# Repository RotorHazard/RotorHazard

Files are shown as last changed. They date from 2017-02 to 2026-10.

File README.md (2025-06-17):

RotorHazard Logo

# RotorHazard
**FPV Race Timing and Event Management**

RotorHazard is an open-source timing and event management system for FPV drone racing. It tracks the video signals broadcast by race drones to trigger lap times, and processes them with a central server (usually a Raspberry Pi). The server's front-end web interface provides race organizer management, pilot/spectator information, and race results. Supports up to 16 simultaneous racers.

> [!TIP]
>Join a community to discuss RotorHazard: [Discord](https://discord.gg/ANKd2pzBKH) | [Facebook](https://www.facebook.com/groups/rotorhazard)
>
> Sponsor RtorHazard's development:[GitHub](https://github.com/sponsors/HazardCreative) | [Patreon](https://www.patreon.com/rotorhazard)

## Features
* Self-contained on local hardware, no internet connection needed
* Server synchronized with user interface for accurate start/end signals; compensates for poor network connectivity
* Connect other systems and extend functionality via [plugins](doc/Plugins.md)
* Server runs on any device supporting Python

### Timing
* Verified accuracy by independent 3rd party testing
* **Never miss a lap**; Recover laps with full accuracy by reviewing race history (marshaling)
* Accurately tracks analog and digital (HD) video transmitters
* Simple visual system calibration before or after a race has completed
* Learns which calibration values work for each pilot and automatically applies them to new races (adaptive calibration)
* Advanced signal filtering allows accurate reading both indoors and outdoors, even in difficult multipathing environments

### Event Management
* Run events with hundreds of pilots and race heats
* Manage pilots, heats, classes, and race formats before or after races are run
* Supports common event/race formats and ranking structures; extensible by plugin
* Statistics broken out by event, class, heat, and round
* Generates overlay displays and results pages for use with live streaming software such as OBS
* LED and audio support indicate race staging, starts, lap times, and other events
* Send live updates of lap times and split times to external systems such as pilot OSD

<br />

## Getting Started

RotorHazard consists of three primary components: Timing hardware, server, and frontend interface. **Most users will begin with RotorHazard by building or buying timing hardware and then installing the server software on it.**

> [!IMPORTANT]
> Live documentation may contain information that does not apply to the current release. For documentation relating to the *current stable version only*, follow the [Documentation](https://github.com/RotorHazard/RotorHazard/releases/latest#documentation) link on the [latest-release page](https://github.com/RotorHazard/RotorHazard/releases/latest).

### Timing Hardware

RotorHazard makes use of a collection of RX5808 video receiver modules. Receivers are tuned to active FPV race channels and monitor their signal strength. A small but dedicated processor (Arduino or STM32) is used to monitor the modules and communicate with the server. Timer builds generally include hardware to run the server as well, making a self-contained unit.

- Choose a style from the available [Build Resources](resources/README.md). Build styles include circuit boards, BOM, and 3D-printable cases.
- [Delta5 Race Timer](https://github.com/scottgchin/delta5_race_timer) hardware is still supported and runs with full accuracy. Replace the Delta5 server software using the current RotorHazard server [setup instructions](doc/Software%20Setup.md), ensuring that you complete a [re-flash of the Arduinos](doc/Software%20Setup.md#rotorhazard-node-code).

### Server

The RotorHazard server aggregates timing signals, handles event structure, calculates results, provides the management interface, and communicates with external timers and systems. It can be run on most systems where Python can be installed, but the recommended and best supported installation is to a **Raspberry Pi**.

> [!NOTE]
> The [RotorHazard Install Manager](https://github.com/RotorHazard/RH_Install-Manager) can greatly simplify installation. Once you have installed the operating system to your SD card, download and run the Install Manager.

> [!IMPORTANT]
> The 'main' branch in the GitHub repository will usually contain the latest development code, which may not be stable. To install or upgrade to the latest stable release, please visit the [latest-release page](https://github.com/RotorHazard/RotorHazard/releases/latest).

### Frontend (Event Management) Interface

The frontend interface is used for event management and viewing results. The server can be accessed by any device (laptop, phone, tablet) with a modern web browser (Firefox, Chrome, Safari) on any operating system (Windows, MacOS, Android, iOS).

- Once the server is running, connect to the server's address using standard IP-based networking.
- All event management is done through the interface.
- No dedicated software or app is necessary to access the interface.

<br />

## Additional Resources

RotorHazard's features and functionality can be greatly extended beyond the core system.

### Plugins

Plugins allow 3rd parties to develop code which runs on the RotorHazard server.
- "Community Plugins" may be found within RotorHazard's interface. From here, plugins are easily downloaded, installed, and upgraded.
- See [Plugins](doc/Plugins.md) for information on manual installation.
- Individual plugins may have specific setup requirements. Read each plugin's documentation before use.

### Wiki

Many additional resources are available from the [Wiki](https://github.com/RotorHazard/RotorHazard/wiki), including extended tutorials, build tools, SD card images, and video content. Browsing these resources is strongly recommended for new users.

<br />

## Feedback

To report bugs or request features, please [post a GitHub issue](https://github.com/RotorHazard/RotorHazard/issues). When reporting issues, use the "Download Logs" button and include the generated '.zip' file.

Community contributions are welcome and encouraged; see [Development](doc/Development.md) for more information.

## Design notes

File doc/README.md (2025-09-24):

# RotorHazard Documentation

## Timing Guides
* [User Guide](User%20Guide.md)
* [Calibration Guide](Tuning%20Parameters.md)
* [Shielding and Course Position](Shielding%20and%20Course%20Position.md)
* [Event Setup Guide](Event%20Setup%20Guide.md)

## System Reference
* [Hardware Setup Instructions](Hardware%20Setup.md)
* [Software Setup Instructions](Software%20Setup.md)
* [Raspberry Pi Reference](Raspberry%20Pi%20Reference.md)
* [Windows Run Script](Windows%20Run%20Script.md)

## Optional Features
* [Plugins](Plugins.md)
* [Split Timing Guide](Cluster.md)
* [USB Nodes](USB%20Nodes.md)

## General Reference
* [FPV Frequency Reference Chart](Frequency%20Reference.md)

<br />

---

* [Build Resources (PCB, etc) &#10132;&#xFE0E;](https://github.com/RotorHazard/RotorHazard/tree/main/resources/README.md)
* [Developer Documentation](Development.md)
* <a href="https://github.com/RotorHazard/RotorHazard">RotorHazard on GitHub &#10132;&#xFE0E;</a>

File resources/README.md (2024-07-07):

# RotorHazard Hardware Build Resources

All supported build styles offer full timing accuracy but differ in size, cost, and ease of use.

<br />

## Full-featured S32_BPill

Standard, current build using the STM32 "Blue Pill" in place of individual Arduinos. Recommended for event managers with the available time and resources to acquire parts and complete the build.

- Supports up to 8 receivers (or more via USB)
- Supports all optional hardware features: current sensing, voltage sensing, RTC, buzzer, Status LED
- Ease-of-use features: power switch, shutdown button

### Full-size
[RotorHazard S32_BPill PCB](S32_BPill_PCB/)<br />
[RotorHazard S32_BPill Case](S32_BPill_case/)

### Compact (supports up to 6 receivers)
[RotorHazard 6 Node STM32](6_Node_BPill_PCB/)<br />
[RotorHazard 6 Node Case](6_node_BPill_case/)

<br />

## NuclearHazard Core

Designed for PCB manufacturer to be able to populate components instead of ordering individually. Available for purchase from the board designer.

- Supports up to 8 receivers (or more via USB)
- Supports buzzer
- Lowest cost self-contained build
- Smallest size
- Simplest assembly

[NuclearHazard Core (Prepopulated S32)](NuclearHazardCore/)

### NuclearHazard Atom

A compact, 2-node version of the NuclearHazard

[NuclearHazard Atom (2-node Prepopulated S32)](NuclearHazardAtom/)

<br />

## Arduino PCB

Uses the same basic hardware as the Delta 5, with improved features and ease of use.

- Supports up to 8 receivers when paired with second PCB (or more via USB)
- Highest cost for required components

[RotorHazard/Arduino PCB](PCB/)<br />
[3D Printed Enclosure for Arduino-based PCBs](enclosure/)

<br />

## Delta 5

Existing Delta 5 builds may be used but are not recommended for new builds.

- Supports up to 8 receivers when paired with second PCB (or more via USB)
- Highest cost for required components
- Arduinos must be manually addressed with code modification
- Arduinos must be removed to reprogram

Replace the Delta5 server software using the current RotorHazard server [setup instructions](doc/Software%20Setup.md), ensuring that you complete a [re-flash of the Arduinos](doc/Software%20Setup.md#rotorhazard-node-code).

<br />

## USB Node

Receivers may be connected to servers via USB insterface.

- Very low cost
- Does not contain server hardware; must connect to an existing server (for example, one of the above builds or installed directly onto a laptop)

[USB Nodes](../doc/USB%20Nodes.md)

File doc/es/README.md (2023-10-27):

# Documentación RotorHazard

## Guías de Configuración
* [Guía de Usuario](User%20Guide.md)
* [Guía de Calibrado](Tuning%20Parameters.md)
* [Blindaje Señal y Posición en Carrera](Shielding%20and%20Course%20Position.md)
* [Guía de Configuración de Evento](Event%20Setup%20Guide.md)

## Referencia del Sistema
* [Instrucciones de Configuración de Hardware](Hardware%20Setup.md)
* [Instrucciones de Configuración de Software](Software%20Setup.md)
* [Raspberry Pi Referencia y Notas](Raspberry%20Pi%20Reference.md)

## Características Opcionales
* [Plugins](Plugins.md)
* [Configuración Cronos Secundarios (Racimo)](Cluster.md)
* [Nodos USB](USB%20Nodes.md)
* [Control de Receptores de Vídeo](Video%20Receiver.md)

## Referencia General
* [Tabla de Referencia de Frecuencias FPV](Frequency%20Reference.md)

<br />

---

* [Recursos de Construcción (PCB, etc.) &#10132;&#xFE0E;](https://github.com/RotorHazard/RotorHazard/tree/main/resources/README.md)
* [Documentación del Desarrollador](Development.md)
* <a href="https://github.com/RotorHazard/RotorHazard">RotorHazard en GitHub &#10132;&#xFE0E;</a>

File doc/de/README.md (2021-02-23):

# RotorHazard-Dokumentation

## Timing-Leitfäden

* [Benutzerhandbuch](User%20Guide.md)
* [Kalibrierungsanleitung](Tuning%20Parameters.md)
* [Abschirmung und Kursposition](Shielding%20and%20Course%20Position.md)
* [Anleitung zur Ereigniseinrichtung](Event%20Setup%20Guide.md)

## System-Referenz

* [Anweisungen zur Hardware-Einrichtung](Hardware%20Setup.md)
* [Software-Einrichtungsanweisungen](Software%20Setup.md)
* [Raspberry Pi Reference](Raspberry%20Pi%20Reference.md)

## Optionale Merkmale

* [Leitfaden zur Zeitaufteilung](Cluster.md)
* [USB-Knoten](USB%20Nodes.md)
* [Video-Empfängersteuerung](Video%20Receiver.md)

## Allgemeine Referenz

* [FPV-Frequenz-Referenzdiagramm](Frequency%20Reference.md)

<br />

---

* [Dokumentation für Entwickler](Development.md)
* <a href="https://github.com/RotorHazard/RotorHazard" target="_blank">RotorGefahr auf GitHub</a> &#10132;➔&#xFE0E;︎

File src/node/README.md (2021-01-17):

# Receiver Node Firmware

The `src/node` directory contains the source code for the RotorHazard nodes. The same code may be used on Arduino nodes, or on an S32_BPill multi-node board.

For Arduino nodes, see '[readme_Arduino.md](readme_Arduino.md)'

For S32_BPill nodes, see '[readme_S32_BPill.md](readme_S32_BPill.md)'

<br>

## Unit Tests

Setup as per <https://github.com/Arduino-CI/arduino_ci>, then

```
set path=c:\Ruby25-x64\msys64\mingw64\bin;%path%
bundle exec arduino_ci_remote.rb --skip-compilation
```

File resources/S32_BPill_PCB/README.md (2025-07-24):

# RotorHazard S32_BPill PCB

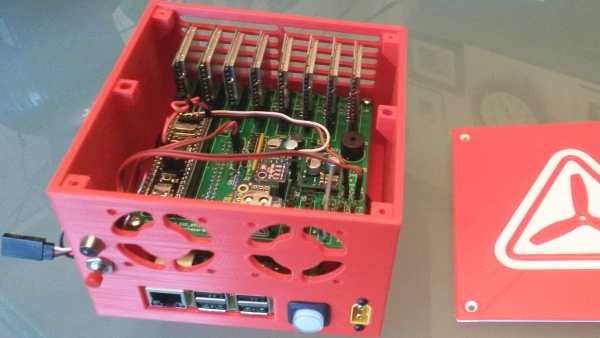
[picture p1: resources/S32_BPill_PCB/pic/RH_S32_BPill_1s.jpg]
RH_S32_BPill_1


The RotorHazard S32_BPill PCB v1.0 represents the next generation of race-timer hardware.

## Features

* Instead of multiple Arduinos, the board has a single STM32 processor

* Board size (100x100mm) is the same as the "standard" Delta5 PCBs

* Supports 1 to 8 RX5808 node modules on a single PCB

* The RX5808 node modules are mounted vertically using small sub-boards -- this allows for up to eight on a single board, and provides substantially improved cooling

* Communication between the STM32 processor and the Raspberry Pi is via serial-port link, running at 921600 baud. The S32_BPill board can also be connected directly to a computer by attaching a USB-to-Serial/FTDI dongle to the J4 (BPill_FTDI) connector, with a baud rate of 921600 or 115200.

* The STM32 processor is on a 40-pin module, attached to the board via sockets. These are commonly known as "Blue Pill" modules, and are readily available and inexpensive (see [below](#aboutblue))

* The board has a 40-pin (2x20) header for connecting to the Raspberry Pi, via a [ribbon cable](https://www.ebay.com/itm/40-Pin-2x20-Female-to-Female-2-54mm-Pitch-40-wire-IDC-Flat-Ribbon-Cable/391776118674) with female ends

* The STM32 processor is in-circuit programmable, able to be updated/flashed using the Raspberry Pi. The update can be performed via the RotorHazard web GUI using the 'Update Nodes' button (in the 'System' section on the 'Settings' page)

* The same server and node source code supports both the S32_BPill and the (existing) multi-Arduino boards

* Supports power/battery monitoring and a buzzer (low-battery alarm)

* Mounting locations for (optional) [DS3231](#rtc) (RTC), [INA219](https://www.adafruit.com/product/904) and [BME280](https://www.amazon.com/Onyehn-Temperature-Humidity-Barometric-Pressure/dp/B07KR24P6P) modules, connected to the Raspberry Pi I2C bus

* Optional "extra" LED, which can be panel mounted on the timer case

* Connector pads for LED-strips: J6 "Pi_LED" (near the middle of the board); pin 1 is ground, pin 2 is signal (going to GPIO10 on the Raspberry Pi)
<br>

Main PCB:<br>
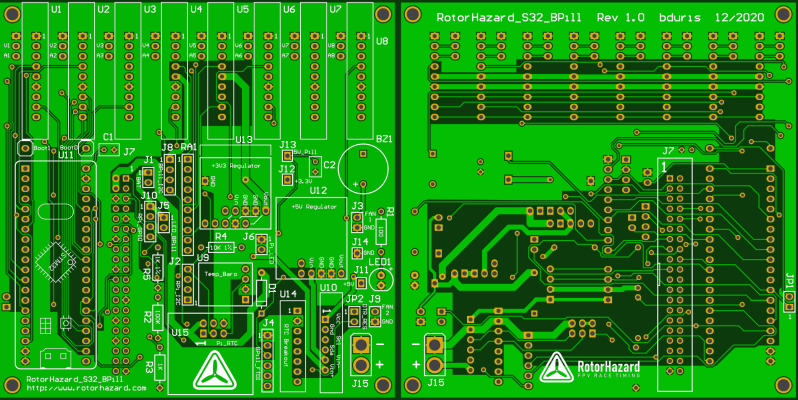
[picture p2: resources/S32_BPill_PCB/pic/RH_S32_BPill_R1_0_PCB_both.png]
RH_S32_BPill_R1_0_PCB_both
<br><br>
Node PCB:<br>
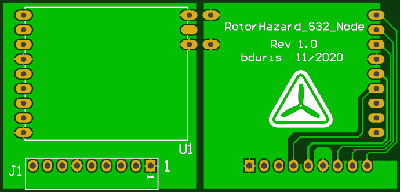
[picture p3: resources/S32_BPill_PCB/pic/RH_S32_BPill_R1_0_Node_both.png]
RH_S32_BPill_R1_0_Node_both


## Resources

[RotorHazard S32_BPill PCB Schematic](files/RotorHazard_S32_BPill_SCH_R1.pdf)

[RotorHazard S32_BPill Node-board Schematic](files/RotorHazard_S32_Node_SCH_R1_0.pdf)

[Gerber files for RotorHazard S32_BPill PCB](http://www.rotorhazard.com/files/GerberFiles_RotorHazard_S32_BPill_R1.zip) &nbsp; (alternate link: [on GitHub](files/GerberFiles_RotorHazard_S32_BPill_R1.zip))

[Gerber files for RotorHazard S32_BPill Node board](http://www.rotorhazard.com/files/GerberFiles_RotorHazard_S32_Node_R1_0.zip) &nbsp; (alternate link: [on GitHub](files/GerberFiles_RotorHazard_S32_Node_R1_0.zip))

The Gerber files can be sent to a PCB manufacturer to fabricate boards. To build a timer, you will need one S32_BPill PCB, and several of the S32_BPill Node boards (one for each RX5808 module in the timer).

The size of the node board is 34.3x33.0mm, with a recommended thickness of 0.8mm (for better thermal conductivity and more capacitance between layers). The recommended thickness for the main PCB is the standard 1.6mm, and, in general, the default PCB-fabrication settings should work well (i.e., 1oz copper, HASL finish, no castellated holes, no gold).

Bill of Materials: [PDF](files/RotorHazard_S32_BPill_R1_bd02.pdf) | [XLS](files/RotorHazard_S32_BPill_R1_bd02.xls) | [HTML](http://www.rotorhazard.com/files/RotorHazard_S32_BPill_R1_bd02.html)

[RotorHazard S32_BPill Main Board Build Guide](mainBoardBuild.md)

[RotorHazard S32_BPill Node Board Assembly](nodeAssembly.md)

[Altium 16.1 project files exported to ASCII](https://github.com/RotorHazard/rhfiles/raw/main/S32_BPill/files/RotorHazard_S32_BPill_R1_AltiumAscii.zip)

[CAD drawings of S32_BPill PCB](https://github.com/RotorHazard/rhfiles/raw/main/S32_BPill/files/RotorHazard_S32_BPill_PCB_R1.pdf)

[CAD drawings of S32_BPill Node Board](https://github.com/RotorHazard/rhfiles/raw/main/S32_BPill/files/RotorHazard_S32_Node_PCB_R1_0.pdf)

[PCB Build Notes](files/Build_notes.txt) and [Pin Soldering Helper](files/PinSolderingHelper.pdf) doc

[Socket Headers](headers.md) and [Trimming Jig](trimjig.md) for RotorHazard S32_BPill

[Generic Blue Pill Pinout](files/GenericBluePillPinout.jpg)

[RobotDyn "Black" Pill Pinout](files/STM32F103C8T6-RobotDyn_Black_Pill_pinout.pdf)

## Notes

* For the S32_BPill board the RotorHazard server must be version 3.1.0 or later.

* The recommended voltage regulators for the board are Pololu [D36V28F5](https://www.pololu.com/product/3782) (5V) and Pololu [D24V22F3](https://www.pololu.com/product/2857) (3.3V). See [here for additional notes](files/PololuCompatibilityWithRaceTimer.txt) about Pololu voltage regulators.

* The board supports two types of [Real-Time Clock](../../doc/Real%20Time%20Clock.md) (RTC) modules - '[DS3231 PiRTC](https://www.adafruit.com/product/4282)' (3x2 header U15) and '[DS3231 Breakout](https://www.adafruit.com/product/3013)' (8-pin header U14). Only one should be attached at a time. See the '[doc/Real Time Clock.md](../../doc/Real%20Time%20Clock.md)' file for setup instructions.

* The recommended installation option for the RX5808 node boards is to use [low-profile sockets](https://www.mouser.com/ProductDetail/Mill-Max/801-93-036-10-012000?qs=WZRMhwwaLl%2F7W%252BkSMqBETQ%3D%3D) in the U1-U8 (9-pin) locations on the PCB. These are shorter and have better contacts than standard socket headers. See the "[Trimming Jig for RotorHazard S32_BPill Nodes](trimjig.md)" document for information about trimming the pins on the node boards.

* An optional [INA219](https://www.adafruit.com/product/904) voltage and current-sensing module may be installed on the PCB at position U10. See [here](https://github.com/RotorHazard/rhfiles/raw/main/S32_BPill/mainBuildPics/image10.jpg) for a pic. (Make sure sure the pin designators correspond to those on the main board -- if the INA219 is installed backwards it will be destroyed.) If an INA219 is not installed, then a wire jumper needs to be soldered between the Vin+ and Vin- pins of the U10 pads (as noted on the
[schematic](https://github.com/RotorHazard/RotorHazard/blob/main/resources/S32_BPill_PCB/files/RotorHazard_S32_BPill_SCH_R1.pdf)).

* If you install the Boot0 [jumper wire](https://www.adafruit.com/product/1951) (and leave it installed) then the Raspberry Pi will always be able to flash the BPill. Without the wire, flash-updates will work if the RotorHazard firmware is operational on the BPill (it has a jump-to-bootloader command), but if not then you'd need to move the 2-pin header clip to the '1' position on Boot0. The red wire in [this pic](pic/RH_S32_BPill_Boot0Jumper.jpg) is the Boot0 jumper wire.

* Note that during the first-time power up, if the buzzer is constantly beeping (because the BPill is not yet flashed), you can put the 2-pin header-clip on the '1' position of the Boot0 jumper on the BPill module and press the reset button to silence it, and leave it on there until the initial flash of the BPill. After that, the Boot0 wire jumper should be installed and left in place. See the links above for BPill pinouts.

* There have been reports that with some BPill modules the buzzer emits a constant tone -- a workaround for this is to wire the '+' side of the buzzer to +3.3V (J12) instead of +5V.  Using a different BPill module may also fix the issue.

* The recommended method for installing the node firmware onto the BPill processor is to use the `Update Nodes` button (in the 'System' section on the 'Settings' page) on the RotorHazard web GUI. The "dtoverlay=miniuart-bt" line needs to have been added to the "/boot/config.txt" file on the RPi for the flash-update to succeed (see instructions in '[doc/Software Setup.md](../../doc/Software%20Setup.md)'). A successful update should result in [messages like these](files/BluePillFlashingMsgs.txt) being displayed and logged.

* If the initial programming of the BPill processor is unsuccessful, it may be necessary to use an [ST-Link](https://www.ebay.com/sch/i.html?_nkw=ST-Link) USB programming adapter. See the instructions in the first section of the '[src/node/readme_S32_BPill.md](../../src/node/readme_S32_BPill.md)' file and use step "[8b](../../src/node/readme_S32_BPill.md#s32stlink)" to do the flash-update.

* The recommended enclosure is the [RotorHazard S32_BPill Case](../S32_BPill_case/README.md), which features mounting holes for a power button, [shutdown button](../../doc/Shutdown%20Button.md), and status LED.

### About Blue Pill Modules

The "Blue Pill" is a module containing an STM32F1 processor and support components mounted on small board with two rows of 20-pin headers. The most common variant is what we're calling the "[Generic Blue Pill](https://stm32-base.org/boards/STM32F103C8T6-Blue-Pill)".

Any Blue Pill module with an STM32F103C8T6 processor and a compatible pin layout should work fine with the S32_BPill PCB. (Note: It needs to be the "C8" module; the STM32F103C6T6 module cannot be used because its available memory space is too small.)

Seaching eBay for "[STM32F103C8T6 Blue Pill](https://www.ebay.com/sch/i.html?_nkw=STM32F103C8T6+Blue+Pill)" should lead to a number of good, cheap options for acquiring compatible modules.

Note that there are other types of modules out there with different pinouts. It is possible (with some tweaking) to use an STM32F4 ("Black Pill") module with the S32_BPill PCB; see [here for more information](stm32f4module.md).

<br>

### Assembled RotorHazard S32_BPill Board

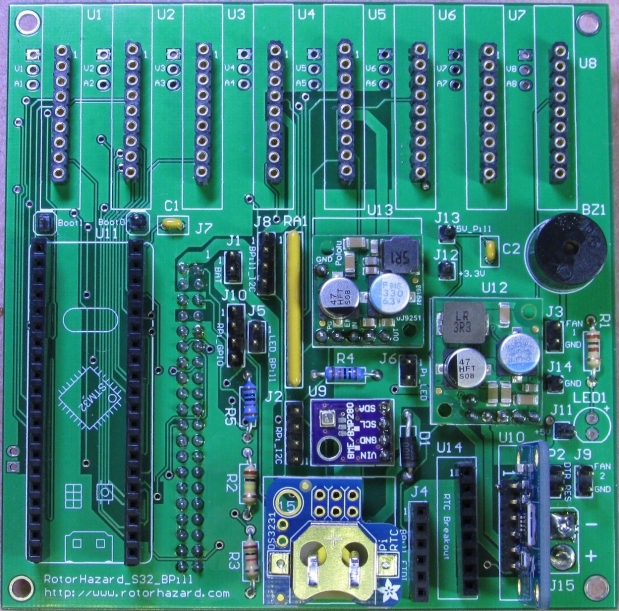
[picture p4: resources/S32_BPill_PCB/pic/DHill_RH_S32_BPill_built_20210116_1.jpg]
DHill_RH_S32_BPill_built_20210116_1


<br>

The RotorHazard S32_BPill schematic and PCB were developed by Bob Duris and [Eric Thomas](http://www.etheli.com).<br>
Special thanks to David Hill for the RotorHazard S32_BPill Main Board Build Guide, and more.

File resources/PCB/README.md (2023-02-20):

# RotorHazard PCB

The RotorHazard PCB 1.2 implements current hardware standards to simplify wiring and component placement, expediting timer builds and improving usability.

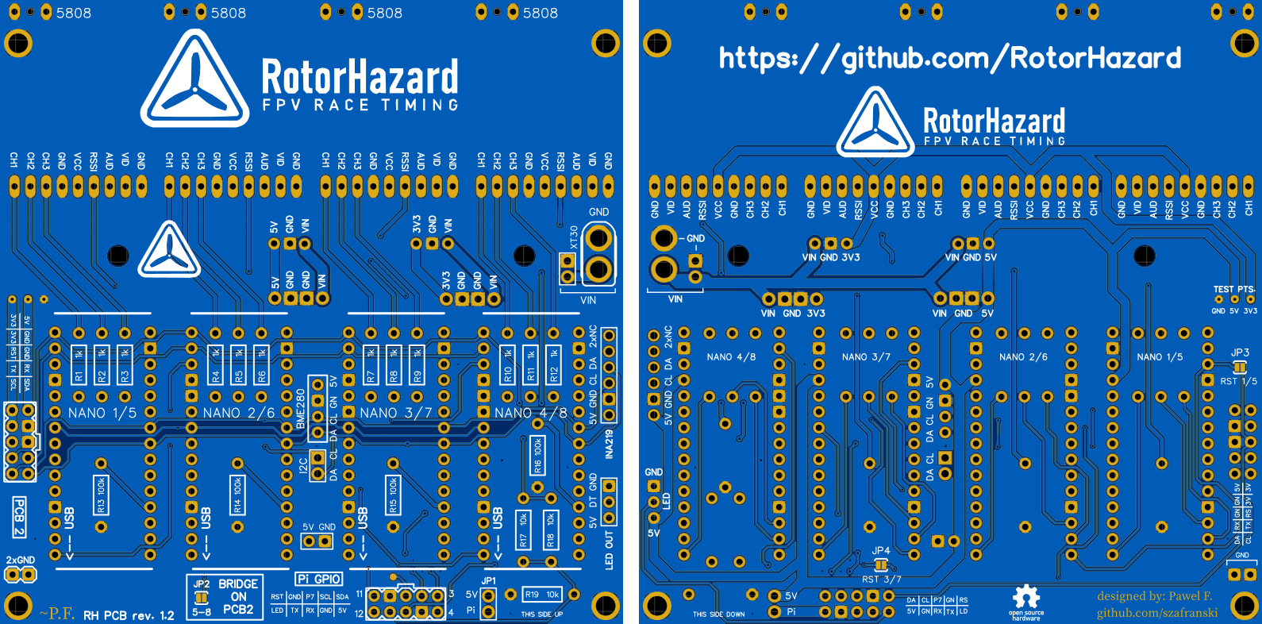
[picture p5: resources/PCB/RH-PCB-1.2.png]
PCB Layout


Download the [gerber file](Gerber_PCB%20RotorHazard%20PCB%20rev.%201.2.zip) to produce a board or send to a PCB manufacturer. Manufacturers often require bulk purchases, so check with other RotorHazard users near you before purchasing in case there is stock available or to split the cost of an order.

[View Board Schematic (PDF)](Schematic_RotorHazard-PCB-1_2_RC_2020-08-20_19-56-33.pdf)<br>
[View Board Dimensions (JPG)](RH_PCB_1_2_dimensions.jpg)

## Features

* 100×100mm (matches common Delta5 V2 PCB)
* Functions as 1–4 node primary board or 1–4 node extension
* Implements hardware-based node address selection. Nodes do not need uniquely addressed and can remain st to address 0 on upload.
* Implements in-system programming wiring for "OTA" updates without removing Arduinos from board
* Integrated voltage converter for ISP line
* Supports standardized 2×5 pin ribbon cable connectors to Pi GPIO and between boards
* Dedicated connectors for BME280 and INA219 sensors
* Expansion connectors for other I2C devices
* Raspberry Pi power isolation jumper
* Additional VIN connector (common uses: case fan or diode for reverse voltage protection)
* Additional ground connectors (common use: case shielding)
* 6 screw-mount holes, 4 with exposed ground plane

## Testing

RotorHazard does not manufacture PCBs and cannot guarantee the quality of any manufacturer. Thoroughly test any boards before connecting sensitive components.

## Build Components

### Required

See [Hardware Setup](https://github.com/RotorHazard/RotorHazard/blob/main/doc/Hardware%20Setup.md) for basic component requirements such as Arduinos, resistors, and receiver modules. The RotorHazard PCB offers mounting points for these components.

In addition to the above building with the RotorHazard PCB requires:
* 1× PCB (for timers with 1–4 nodes) or 2× PCB (timers with 5–8 nodes)
* 1× 3V 2.5A regulator
* 3× 10k resistor (0.25W or greater)

The RotorHazard PCB is designed to fit the following components:
* Arduino Nano
* Pololu D24V25F5 ("enable" pin is not connected)
* Pololu D24V25F3 ("enable" pin is not connected)

### Recommended

These components improve performance or significantly improve ease of use.

* 2×15 pin female 0.1in headers for each Arduino
* 1×9 pin female 0.1in header for each RX5808 module
* Female 0.1in header for each voltage regulator (either 1×3 pin or 1×4 pin depending on regulator style)
* 1×2 pin male 0.1in header with 2-pin jumper (for disconnecting power from the Pi)
* 2×5 pin male connector for Pi GPIO (may be KANDA/ISP style or male gold-pin header)
* Flat/ribbon cable or 10pcs jumper wires (2×5) for Pi GPIO
* 4–6 3mm screws for each board (mounting board to case)

If a 2nd PCB is used:
* 2×5 pin male connector for each PCB
* Flat/ribbon cable or 10pcs jumper wires (2×5) for PCB1 -> PCB2

### Optional

For a tidy build or to use with optional features, the following components may be added.

* XT30 female connector (power in)
* 1×3 pin female 0.1in header for each RX5808 module's antenna connector—do not solder center ANT pin
* 1×3 pin male 0.1in header for LEDs (connect only DATA and GND if LED are powered with separate voltage source)
* 1×6 pin female 0.1in header for INA219 sensor
* 1×4 pin female 0.1in header for BME280 sensor
* 1×2 0.1in header for grounding of RF shield (not needed if mounting screws are already connected to RF shield)
* 1×2 0.1in header for connecting optional accessories to the VIN (such as a 12V case fan)

## Assembly

This layout can be used as a primary board for up to 4 nodes when directly connected to the Pi, or a secondary board for up to 4 additional nodes. When connected directly it will be referred to as PCB1. If you are using only one board, follow all instructions for PCB1. A secondary board is referred to as PCB2.

* Find "THIS SIDE UP" indicator. This is the expected side on which to attach your components. While other configurations are possible, you will need to adjust these assembly instructions accordingly.
* Use node slots in numeric order. While RotorHazard should function with nodes placed out of order, in-system node flashing may not.
* Solder four resistors at "R" positions within each node area for all nodes you will be using. Use the values indicated (1k or 100k).
* R17-19 are required on PCB1. They are not used for PCB2.
* Female 0.1" (2.54mm) headers are expected for Arduino mounts, voltage regulators, and RX5808 mounts. Add these headers now if you are using them. If you choose to flush mount any component, be sure to electrically isolate it from the board.
* Bridge JP1 on PCB1. A physical jumper is recommended in this position. Bridging on PCB2 is not required.
* If using 5–8 nodes, connect "PCB2" headers between each board, being careful to match polarity. You may use a standard 2×5 pin ribbon cable or wire these insidivdually. On PCB2, bridge pads at the bottom marked "BRIDGE ON PCB2" (JP2)
* If using an odd number of nodes, bridge one and only one pad on the back of one board that corresponds to the highest numbered node in use:
  * 1 node: PCB1 JP3
  * 3 nodes: PCB1 JP4
  * 5 nodes: PCB2 JP3
  * 7 nodes: PCB2 JP4
* If using an even number of nodes, do not bridge JP3 and JP4.
* Connect a 5V voltage regulator and a 3.3V regulator on PCB1. Use either the upper (3) or lower (4) set of pins depending on the chosen regulator's pinout. Do not use both upper and lower sets at once for the same voltage.
* Connect input voltage connector or wires at VIN. Use XT30 connector if desired.
* STOP. Perform continuity testing to ensure there are no shorts from power to ground. Connect power at VIN and test 5V, 3.3V, and GND at test points on back of board before proceeding. Use a fuse or "smoke stopper" during these tests.
* Connect the Pi to the "Pi GPIO" header block. You may use a 2×5 pin cable attached to pins 3–12 of the Pi GPIO, or individual wires if you wish to change any connections (such as for "LED IN")
* If using INA219 or BME280 sensors, connect to dedicated pads.
* Connect Arduinos. Keep Aruino reset button and LEDs visible. Keep USB connector toward side indicated with "<-- USB" (away from voltage regulators).
* Connect RX5808 modules. Optionally connect GND pads near antenna. Do not solder to RX5808 antenna connection (center pad).
* When connecting an LED strip to LED OUT, ensure the voltage regulator you are using is rated highly enough for all Arduinos, sensors, and the LED strip combined. If not, supply power for the LEDs from a separate regulator, using only data and ground from the PCB.

## Usage

* Before ISP flashing of nodes is possible, nodes must not be transmitting over serial. You can flash the most recent node version from RotorHazard, or the standard "Blink" sketch. (Delta5 and older RotorHazard node versions generally use serial and will prevent ISP from functioning.)
* Nodes should all be flashed with the node number of 0 (default). This board will automatically assign node numbers based on their position.
* In-system flashing can be accomplished with the [OTA tool](https://github.com/szafranski/RH-ota)
* If flashing nodes by USB, disconnect JP1 to prevent powering on the Pi.

## Credit

This board and the OTA tool were developed by [Paweł Fabiszewski](mailto:p.fabiszewski@gmail.com).

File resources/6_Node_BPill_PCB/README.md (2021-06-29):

# RotorHazard 6 Node STM32

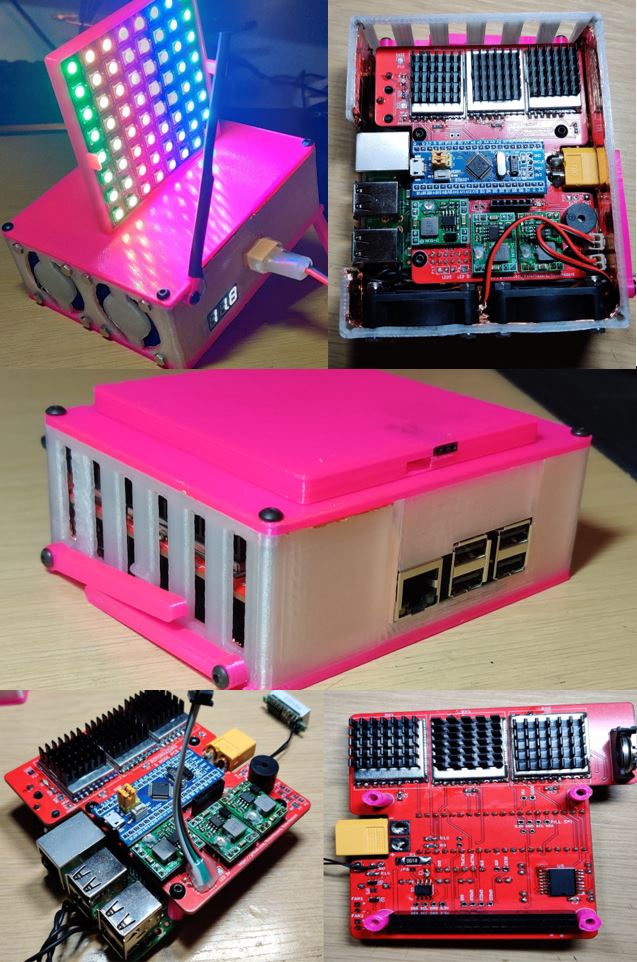
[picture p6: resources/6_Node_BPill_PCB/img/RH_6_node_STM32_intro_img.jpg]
RH_6_node_STM32_intro_img


## Features

* Supports 1 to 6 RX5808 nodes
* Board size is 97mmx87mm, with cut-outs for an XT60 & Raspberry Pi connectors
* The Raspberry Pi plugs directly into the PCB in a raspberry Pi 'hat' style, to keep things compact
* Instead of multiple Arduinos, the board uses a single STM32 processor on a 40 pin module, mounted on the PCB
* The STM32 firmware can be updated via the RotorHazard web GUI using the 'Update Nodes' button (in the 'System' section on the 'Settings' page)
* The same server and node source code supports both the 6 node STM32 and the (existing) multi-Arduino boards
* Supports power / battery monitoring and a buzzer (low-battery alarm)
* INA219 (Current sense IC) & DS3231 (Real Time Clock) + RTC battery can be mounted directly to the PCB
* Connector pads for LED-strips & dedicated regulator
* Fans can be automatically switched on based on raspberry pi temperature.

PCB build instructions can be found [here](BoardBuild.md)

PCB:<br>
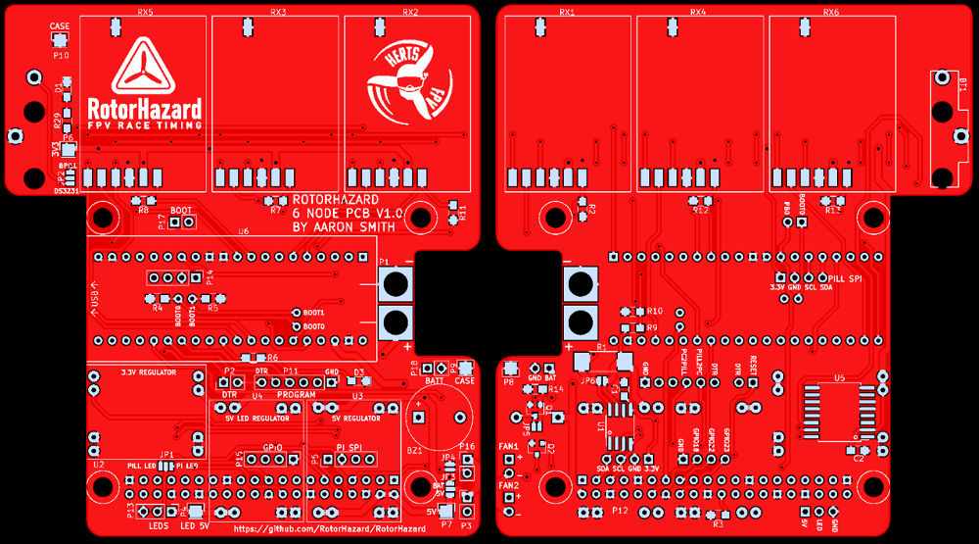
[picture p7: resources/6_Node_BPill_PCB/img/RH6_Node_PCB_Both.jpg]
RH6_Node_PCB_Both


## Cost
The cost of the required parts is approximately £74 (~102.60 USD)

For each node add £6, so all 6 nodes would add £36 (~49.90 USD)

All the optional parts add approximately £23 (~31.90 USD)

To fit all parts to the board will cost approximately £133 (~184.40 USD)

Note: The above costs includes the raspberry pi 3b + SD card. Mouser & Banggood were used in the above costings, parts may be cheaper from other suppliers

## Bill of Materials (BOM)
The PDF version of the BOM can be found [here](RotorHazard_6_Node_Timer_BOM_V1.0.pdf), the PDF version contains more information and suggested parts / suppliers
### Required

For the PCB:
Reference                       | Quantity  | Part No.                                                           | Notes
--------------------------------|-----------|--------------------------------------------------------------------|---------
PCB                             |   1       | Download the [gerber files](RotorHazard_6_Node_Timer_fab_V1.0.zip) | You can upload the gerbers files to your favourite PCB supplier or click [here](https://www.pcbway.com/project/shareproject/RotorHazard_6_Node_STM32_Lap_Timer.html) to buy from PCBway<br>Keep default options but consider changing:<br>- The solder mask colour <br>- Select quantity 10 which doesn't cost any more
P12	                            |   1	    | 2.54mm 20x2 8.51mm tall header                                     | Single strips also work
P1	                            |   1	    | XT60 Male	                                                         | -
R2, R7, R8, R9, R11, R12, R13	|   7	    | 100k ohm 5% 0805 resistor                                          | Buy some extra in case you drop one
R3, R10                         |   2       | 10k ohm 5% 0805 resistor                                           | Buy some extra in case you drop one
U2, U3                          |   2	    | MP1584	                                                         | -
U2, U3  	                    |   16	    | 2.54mm header pins                                                 | -
U6	                            |   1	    | STM32F103C8T6 	                                                 | -
RX1, RX2, RX3, RX4, RX5, RX6    |   1-6	    | RX5808	                                                         | 1 of these is required for each node you wish to fit

For the timer assembly:
Name                            | Quantity  | Notes
--------------------------------|-----------|---------
RASPBERRYPI_3B+                 |   1       | Alternative: Raspberry Pi 4
8GB+ Micro SD card              |   1       | Any Micro SD card between 8GB and 64GB will work
  
You will also require some 3D printed parts for the case and the 11.5mm 3D printed stand offs. If you wish to use a different case then 12mm standoffs should work.

Details on 3D printed parts and mechanical assembly can be found [here](../6_node_BPill_case/README.md)
  
### Optional
For the PCB:
Reference                       | Quantity  | Part No.                      | Notes
--------------------------------|-----------|-------------------------------|---------
U5                              |	1	    | DS3231SN                      | Fit if you want the real time clock (RTC), alternatives: DS3231S#T&R, DS3231SN#, DS3231S#
BT1	                            |   1	    | Keystone Electronics 1069     | Fit if you want the real time clock (RTC)
BT1	                            |   1	    | CR1632 battery                | Fit if you want the real time clock (RTC), alternatives: CR1620, CR1616
R1	                            |   1	    | 0.1 ohm 2512 1% resistor      | Fit if you wish to use the current sense IC
U1	                            |   1	    | INA219AIDR	                | Fit if you wish to use the current sense IC, alternatives: INA219AID, INA219BID, INA219BIDR
C1, C2	                        |   2	    | 100nF X7R 0805 capacitor      | These are decoupling capacitors for INA219 and DS3231
D1, D3	                        |   2	    | 0805 LED       	            | Fit if you want the on-board power and status LED's, not really needed
R6, R29	                        |   2	    | 220 ohm 5% 0805 resistor	    | Fit if you want the on-board power and status LED's, not really needed
P4	                            |   1	    | 3 pin JST SM Female	        | Fit if you want to use RGB LED rope / tape
U4	                            |   8	    | 2.54mm header pins            | Fit if you want to use RGB LED rope / tape
U4	                            |   1	    | MP1584	                    | Fit if you want to use RGB LED rope / tape
BZ1	                            |   1       | 12mm x 9.5mm 5V buzzer        | Used for low voltage alarm
Q2  	                        |   1	    | GSD SOT-23 N-Channel MOSFET   | Used for optional fan enable control, an example is IRLML6344TRPBF

For the timer assembly:
Name	                        | Quantity      | Notes
--------------------------------|---------------|---------
Raspberry Pi heat syncs         |   1 set       | Recommended to keep the pi cool
20x20x6mm heat sync             |   1-6         | Recommended to keep the RX5808's cool
Thermal glue                    |   1 tube      | Needed to attach the RX5808 heat syncs
LCD Voltage Screen              |   1           | Used to show the battery voltage on the case

## Tools
### Required
1. Soldering iron (chisel tip recommended to fit INA219 or DS3231 IC's)
2. Solder
3. Tweezers
4. Digital Multi Meter (DMM), to measure voltage and resistance
5. Screw driver for screws purchased
6. Small flat head screw driver to adjust MP1584 voltage

### Recommended
1. Wire cutters / side cutters
2. Helping hands
3. Solder wick
4. Hot glue & glue gun
5. Pilers
6. Insulation tape
7. Copper tape with conductive adhesive
8. Magnifying glass

## Resources

[RotorHazard 6 Node STM32 Schematic](RotorHazard_6_Node_Timer_V1.0.pdf)

[Gerber files for RotorHazard 6 Node STM32 PCB](RotorHazard_6_Node_Timer_fab_V1.0.zip)

[RotorHazard 6 node STM32 Board Build Guide](BoardBuild.md)

[3D printed parts & mechanical assembly](../6_node_BPill_case/readme.md)

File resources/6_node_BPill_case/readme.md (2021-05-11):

# 6 Node PCB Case
Internet connection is required to view images

## 3D Parts
Click [here](https://github.com/RotorHazard/rhfiles/tree/main/6_Node_BPill/case/stl) to view and download the .stl files

The 3D designs are done using Sketchup 2017 and the stl export plugin (which is hard to get hold of now). The .skp files have been uploaded should you wish to modify them, they can be found [here](https://github.com/RotorHazard/rhfiles/tree/main/6_Node_BPill/case/skp)

The available parts are:
Part                                    | Description                                                             | Links
----------------------------------------|-------------------------------------------------------------------------|-------------------------------------------------
RotorHazard Case                        | This is the main part of the case                                       | [[view](https://github.com/RotorHazard/rhfiles/blob/main/6_Node_BPill/case/stl/RotorHazard_Case.stl)] [[stl](https://github.com/RotorHazard/rhfiles/raw/main/6_Node_BPill/case/stl/RotorHazard_Case.stl)] [[skp](https://github.com/RotorHazard/rhfiles/raw/main/6_Node_BPill/case/skp/RotorHazard_Case.skp)]
RotorHazard Leg 60mm                    | This is the leg for the case, 2 are required                            | [[view](https://github.com/RotorHazard/rhfiles/blob/main/6_Node_BPill/case/stl/RotorHazard_Leg_60mm.stl)] [[stl](https://github.com/RotorHazard/rhfiles/raw/main/6_Node_BPill/case/stl/RotorHazard_Leg_60mm.stl)] [[skp](https://github.com/RotorHazard/rhfiles/raw/main/6_Node_BPill/case/skp/RotorHazard_Leg_60mm.skp)]
RotorHazard Standoff M2.5 11.5mm        | This is a standoff to go between the pi and the PCB, 4 are required     | [[view](https://github.com/RotorHazard/rhfiles/blob/main/6_Node_BPill/case/stl/RotorHazard_Standoff_M2.5_11.5mm.stl)] [[stl](https://github.com/RotorHazard/rhfiles/raw/main/6_Node_BPill/case/stl/RotorHazard_Standoff_M2.5_11.5mm.stl)] [[skp](https://github.com/RotorHazard/rhfiles/raw/main/6_Node_BPill/case/skp/RotorHazard_Standoff_M2.5_11.5mm.skp)]
RotorHazard Standoff M3 11.5mm          | Same as above, use these if you have made your pi's fixing holes wider  | [[view](https://github.com/RotorHazard/rhfiles/blob/main/6_Node_BPill/case/stl/RotorHazard_Standoff_M3_11.5mm.stl)] [[stl](https://github.com/RotorHazard/rhfiles/raw/main/6_Node_BPill/case/stl/RotorHazard_Standoff_M3_11.5mm.stl)] [[skp](https://github.com/RotorHazard/rhfiles/raw/main/6_Node_BPill/case/skp/RotorHazard_Standoff_M3_11.5mm.skp)]
RotorHazard Antenna Holder 50mm         | Used to mount the wired antenna                                         | [[view](https://github.com/RotorHazard/rhfiles/blob/main/6_Node_BPill/case/stl/RotorHazard_Antenna_Holder_50mm.stl)] [[stl](https://github.com/RotorHazard/rhfiles/raw/main/6_Node_BPill/case/stl/RotorHazard_Antenna_Holder_50mm.stl)] [[skp](https://github.com/RotorHazard/rhfiles/raw/main/6_Node_BPill/case/skp/RotorHazard_Antenna_Holder_50mm.skp)]
RotorHazard Lid No LED's                | The case lid with no cut outs for LED's                                 | [[view](https://github.com/RotorHazard/rhfiles/blob/main/6_Node_BPill/case/stl/RotorHazard_Lid_No_LEDs.stl)] [[stl](https://github.com/RotorHazard/rhfiles/raw/main/6_Node_BPill/case/stl/RotorHazard_Lid_No_LEDs.stl)] [[skp](https://github.com/RotorHazard/rhfiles/raw/main/6_Node_BPill/case/skp/RotorHazard_Lid_No_LEDs.skp)]
RotorHazard Lid External LED's          | The case lid with a cut out for a 3 pin JST-SM connector                | [[view](https://github.com/RotorHazard/rhfiles/blob/main/6_Node_BPill/case/stl/RotorHazard_Lid_External_LEDs.stl)] [[stl](https://github.com/RotorHazard/rhfiles/raw/main/6_Node_BPill/case/stl/RotorHazard_Lid_External_LEDs.stl)] [[skp](https://github.com/RotorHazard/rhfiles/raw/main/6_Node_BPill/case/skp/RotorHazard_Lid_External_LEDs.skp)]
RotorHazard Lid Cartridge 1 Part        | The case lid with an aperture for the LED cartridge                     | [[view](https://github.com/RotorHazard/rhfiles/blob/main/6_Node_BPill/case/stl/RotorHazard_Lid_Cartridge_1part.stl)] [[stl](https://github.com/RotorHazard/rhfiles/raw/main/6_Node_BPill/case/stl/RotorHazard_Lid_Cartridge_1part.stl)] [[skp](https://github.com/RotorHazard/rhfiles/raw/main/6_Node_BPill/case/skp/RotorHazard_Lid_Cartridge_1part.skp)]
RotorHazard Lid Cartridge 2 part A      | As above but broken into two easy to print parts, this is part A        | [[view](https://github.com/RotorHazard/rhfiles/blob/main/6_Node_BPill/case/stl/RotorHazard_Lid_Cartridge_2part_A.stl)] [[stl](https://github.com/RotorHazard/rhfiles/raw/main/6_Node_BPill/case/stl/RotorHazard_Lid_Cartridge_2part_A.stl)] [[skp](https://github.com/RotorHazard/rhfiles/raw/main/6_Node_BPill/case/skp/RotorHazard_Lid_Cartridge_2part_A.skp)]
RotorHazard Lid Cartridge 2 part B      | As above but broken into two easy to print parts, this is part B        | [[view](https://github.com/RotorHazard/rhfiles/blob/main/6_Node_BPill/case/stl/RotorHazard_Lid_Cartridge_2part_B.stl)] [[stl](https://github.com/RotorHazard/rhfiles/raw/main/6_Node_BPill/case/stl/RotorHazard_Lid_Cartridge_2part_B.stl)] [[skp](https://github.com/RotorHazard/rhfiles/raw/main/6_Node_BPill/case/skp/RotorHazard_Lid_Cartridge_2part_B.skp)]
RotorHazard Cartridge                   | This is the cartridge to hold the 8x8 LED panel                         | [[view](https://github.com/RotorHazard/rhfiles/blob/main/6_Node_BPill/case/stl/RotorHazard_LED_Cartridge.stl)] [[stl](https://github.com/RotorHazard/rhfiles/raw/main/6_Node_BPill/case/stl/RotorHazard_LED_Cartridge.stl)] [[skp](https://github.com/RotorHazard/rhfiles/raw/main/6_Node_BPill/case/skp/RotorHazard_LED_Cartridge.skp)]
RotorHazard Case (Pi zero / banana pi)  | Use this case with a pi zero or banana pi (No USB or Ethernet cutouts)  | [[view](https://github.com/RotorHazard/rhfiles/blob/main/6_Node_BPill/case/stl/RotorHazard_Case%20-%20pi%20zero.stl)] [[stl](https://github.com/RotorHazard/rhfiles/raw/main/6_Node_BPill/case/stl/RotorHazard_Case%20-%20pi%20zero.stl)] [[skp](https://github.com/RotorHazard/rhfiles/raw/main/6_Node_BPill/case/skp/RotorHazard_Case%20-%20pi%20zero.skp)]
RotorHazard Standoff M3 13.1mm          | Use this standoff when the screw doesn't go through the pi              | [[view](https://github.com/RotorHazard/rhfiles/blob/main/6_Node_BPill/case/stl/RotorHazard_Standoff_M3_13.1mm.stl)] [[stl](https://github.com/RotorHazard/rhfiles/raw/main/6_Node_BPill/case/stl/RotorHazard_Standoff_M3_13.1mm.stl)] [[skp](https://github.com/RotorHazard/rhfiles/raw/main/6_Node_BPill/case/skp/RotorHazard_Standoff_M3_13.1mm.skp)]

## Parts to buy for the case
### Required
Part                | Qty   | Description
--------------------|-------|---------------
M3x8mm              | 10    | Used to attach the PCB to the standoffs, the lid to the case and the legs to the case
M3x10mm countersunk | 4     | Used to attach the Raspberry pi to the case
Copper tape         | -     | Used for RF shielding, make sure it has conductive adhesive
26AWG Wire          | -     | 

### Optional
Part                    | Qty   | Description
------------------------|-------|---------------
M3x5mm                  | 1     | Used for attaching the antenna arm, 3x8mm would work
M2x5mm                  | 2     | Used to attach the voltage display to the case
40x40x10mm fans         | 2     | 
M3x16mm                 | 8     | Attaches the fans to the case
M3 nut                  | 8     | Attaches the fans to the case
8x8 WS218b LED panel    | 1     | LED's for the cartridge print
2.54mm header 3 pins    | 2     | Connects the cartridge to the lid
2.54mm socket 3 pins    | 1     | Connects the cartridge to the lid
Hot glue                | -     | To attach cartridge pins to case

## Lid
There are 3 lid option to chose from:
1. The first has no LED apparatuses and is a basic lid
2. The second adds an aperture for the female JST-SM 3 pin header that comes with the LED's so that external LED's can be used
3. The third allows use of an LED cartridge, the print can be printed in 1 or 2 parts depending on your printers capabilities

### LED cartridge & lid wiring
The LED cartridge connects to the lid using standard PCB mount 2.54mm headers and sockets. You have to be careful to get the alignment of the connectors correct.

1. Start with the two 3 way pin headers, solder wire to both of them and then solder those wires together.
2. Now insert those headers into the two holes on the lid 3D print. Make sure the pin out is symmetrical to ensure correct connections when you rotate the cartridge
3. Now solder the socket to wire and fit it into the LED cartridge print
4. Now is the time to align the connectors. Put the cartridge into the cartridge insert in the lid and ensure a good connection with the lids pins. Hot glue into place once aligned.
5. Rotate the cartridge and ensure it fits in the other orientation.
6. Now solder the cartridge socket wires to the LED panel and secure in place

Internet connection is required to view images
Internet connection is required to view images

## Thermal Considerations
Commercial electronics are typically rated up to 70&deg;C. During initial testing the timer was around 45&deg;C above ambient, with all 6 nodes active and with heat-syncs fitted.

Whilst this is still within 70&deg;C at room temperature ~21&deg;C these kind of temperatures are not recommended as it can cause the following:
* Stability issues
* Reduced life span of the electronics

If you live in a cold country or only plan to use 2-3 nodes at the same time then you are probably ok just using heat-syncs

For the majority of people heat-syncs and fans are recommended for optimum cooling.

If you use fans and wish for them to activate automatically and save power + maintain a constant temperature go [here](https://github.com/Aaronsss/Raspberry-Pi-Fan-Control) and follow the install instructions for the automatic fan control which will turn fans on when the pi temperature is 40&deg;C and off again when it is 38&deg;C

## RF Shielding
RF shielding is an essential part of RotorHazards timing, make sure you shield your timer. There are a number of ways to do this like putting the timer in a metal box

The neatest way to do it is to get some copper tape and cover the inside of the box. Be sure to use copper tape with conductive adhesive. Once fitted you can solder a wire to the copper tape and then connect that to the case pads of the PCB. It is recommended to add insulation tape in locations where the PCB comes close to the case. Be sure to leave the end with the grill and centers of the fan covers unshielded

More information of RF shielding can be found [here](/doc/Shielding%20and%20Course%20Position.md)

Internet connection is required to view images

## Wifi Antenna Wiring
If you wish to use Wifi it is recommended to use a USB 2.4GHz wifi dongle with external antenna. 

You can then go one step further and de-case it and include it inside the laptimer case. This is what the arm is designed for on this case design.

Remove the plastic casing from the wifi dongle, then de-solder the SMA connector. Now solder a 2.4GHz antenna to the old SMA pads by either direct soldering or using a U.FL connector

Now connect the USB connections to the probe points on the bottom of the Raspberry Pi. On a Raspberry Pi 3B+ the probe points are as follows for the bottom left USB (when looking directly at the USB connector):
* PP27 = USB VCC
* PP42 = USB D-
* PP43 = USB D+
* PP51 = GND

You should then apply heat shrink to the wifi board and apply some hot glue to the antenna end for mechanical security.

Now you can feed the antenna through the hole in the case and heat shrink it to the antenna arm

You will then need to configure your pi to use the wifi dongle instead of the built in wifi

Internet connection is required to view images

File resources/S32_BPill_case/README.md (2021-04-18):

# RotorHazard S32_BPill Case

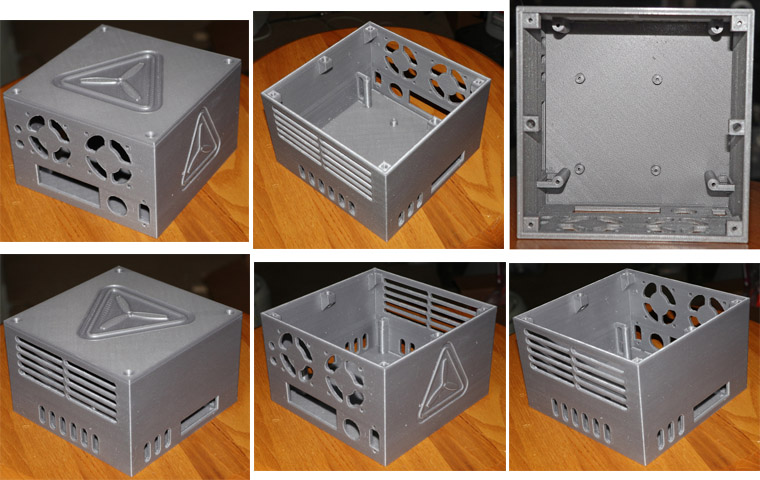
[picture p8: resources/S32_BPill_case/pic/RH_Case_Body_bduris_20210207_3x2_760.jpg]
RH_Case_Body_3x2


The RotorHazard S32_BPill case is the recommended enclosure to use with the [S32_BPill PCB](../S32_BPill_PCB/README.md). Inspired by existing designs, the S32_BPill case was created from scratch as a new project using [FreeCAD](https://github.com/FreeCAD/FreeCAD).

## Features

* Four mounting posts for attaching the S32_BPill PCB with screws (no separate mounting tray)

* Mounting posts for the Raspberry Pi on the bottom, with openings on the front and side for accessing Pi connectors

* Contains mounting holes for a power button, [shutdown button](../../doc/Shutdown%20Button.md), status LED, and (optional) fans

* Lid may be attached with screws, or magnets may be installed in provided mounts

* FreeCAD source project file available (see below)

## Resources

[RotorHazard S32_BPill Case Body \(with logo, 77mm tall\)](https://github.com/RotorHazard/rhfiles/raw/main/S32_BPill/case/RotorHazardCaseBodyBD77.stl) \[[preview](https://github.com/RotorHazard/rhfiles/blob/main/S32_BPill/case/RotorHazardCaseBodyBD77.stl)\]

[RotorHazard S32_BPill Case Lid \(with logo\)](https://github.com/RotorHazard/rhfiles/raw/main/S32_BPill/case/RotorHazardCaseTopBDyy.stl) \[[preview](https://github.com/RotorHazard/rhfiles/blob/main/S32_BPill/case/RotorHazardCaseTopBDyy.stl)\]

[FreeCAD Source Project File](https://github.com/RotorHazard/rhfiles/raw/main/S32_BPill/case/RotorHazardCaseBDyy.FCStd)

[Detailed RotorHazard S32_BPill Case Build Guide](detailedCaseBuild.md) (alt [PDF version](https://github.com/RotorHazard/rhfiles/blob/main/S32_BPill/case/RH_S32_BPill_CaseBuildInstructions.pdf))

Note: The 77mm-tall case is a good fit with the "standard" RotorHazard S32_BPill PCB build using [low-profile socket headers](../S32_BPill_PCB/headers.md) for the node modules. If standard socket headers are used for the node modules then the 81mm-tall case (below) can provide the extra height needed.

[RotorHazard S32_BPill Case Body \(with logo, 81mm tall\)](https://github.com/RotorHazard/rhfiles/raw/main/S32_BPill/case/RotorHazardCaseBodyBD81.stl) \[[preview](https://github.com/RotorHazard/rhfiles/blob/main/S32_BPill/case/RotorHazardCaseBodyBD81.stl)\]

[RotorHazard S32_BPill Case Body \(without logo, 77mm tall\)](https://github.com/RotorHazard/rhfiles/raw/main/S32_BPill/case/RotorHazardCaseBodyBD77_NoLogo.stl) \[[preview](https://github.com/RotorHazard/rhfiles/blob/main/S32_BPill/case/RotorHazardCaseBodyBD77_NoLogo.stl)\]

[RotorHazard S32_BPill Case Body \(without logo, 81mm tall\)](https://github.com/RotorHazard/rhfiles/raw/main/S32_BPill/case/RotorHazardCaseBodyBD81_NoLogo.stl) \[[preview](https://github.com/RotorHazard/rhfiles/blob/main/S32_BPill/case/RotorHazardCaseBodyBD81_NoLogo.stl)\]

[3D CAD Rendering of RotorHazard S32_BPill Case Body](files/RotorHazard_S32_BPill_Case_3D.pdf)

## Notes

* The case top will probably print best if it is inverted on the print bed.

* Changes to the design may be implemented by editing the FreeCAD source project file and regenerating the STL files. The design is highly parameterized and many of the dimensions can be altered by simply changing a number in the spreadsheet that is part of that source project.

* A page for this case has been posted on Thingiverse: https://www.thingiverse.com/thing:4733410

<br>

The RotorHazard S32_BPill case and detailed build guide were developed by Bob Duris

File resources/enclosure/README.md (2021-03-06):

# 3D Printed Enclosure
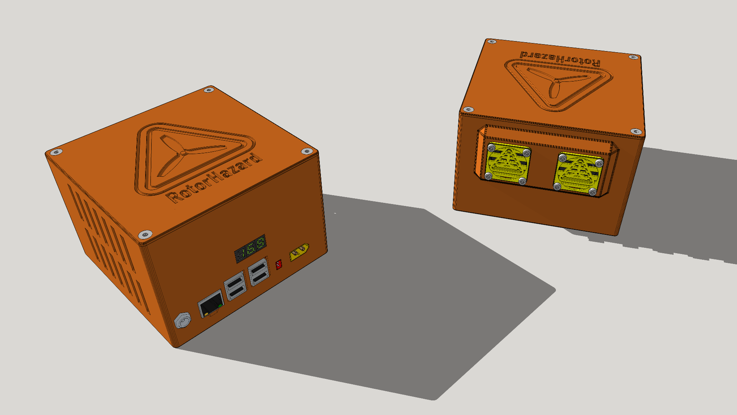
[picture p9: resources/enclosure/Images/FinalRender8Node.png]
3D rendering of box with openings for Raspberry Pi, case fans, and voltage display; with RotorHazard branding


## **Four and Eight Node Printable Enclosures**
This is pretty much a ground up rework of FreeFormFPV's excellent original work. Not much of the original remains. I've expanded heavily on the original design and hopefully improved it.

There are two enclosures. One for four node timers and one for eight node timers. The lid and PCB tray fit either.

The Original D5 100x100mm V2.0 PCB is a 'click fit' into the new PCB Trays. No fasteners needed. the trays then stack in place in the enclosure and are secured in place by the lid. Which secures with four countersunk M3 fasteners. The planned updated RotorHazard PCB will be compatible with the PCB tray.

A POE DC jack is provided so that the timer can be powered at the other end of the network cable (POE injector needed). Be sure to use a THREE PIN DC jack wired properly to disconnect the XT60 socket when in use. Failure to do this may result in the release of magical smoke. The timer may thus be powered either locally by a lipo or remotely over POE.

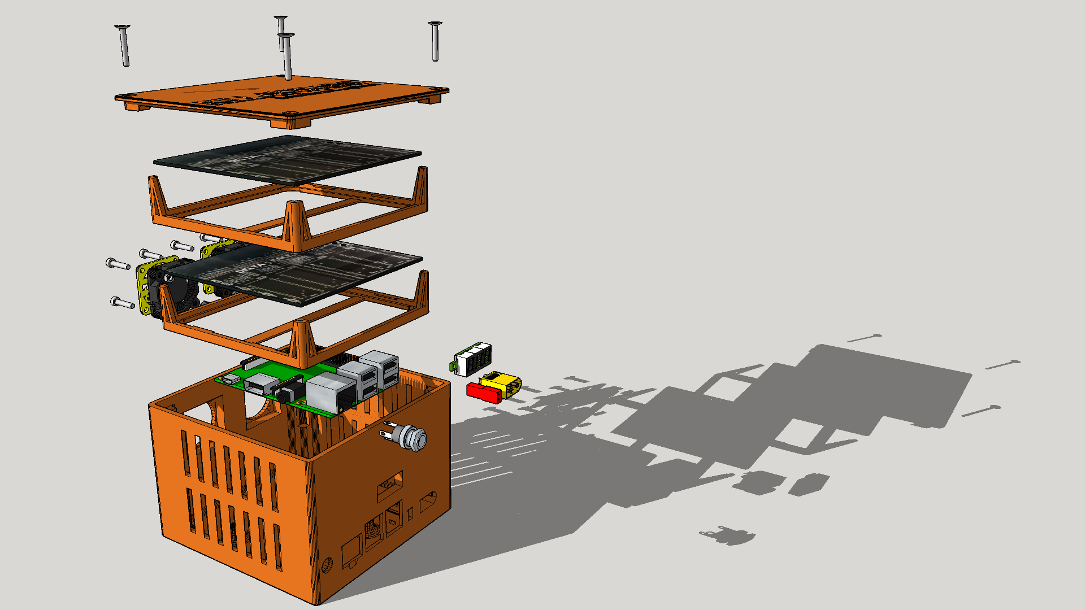
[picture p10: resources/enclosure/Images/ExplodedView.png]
Exploded view of enclosure with insert trays and electronic components

## **Printable Parts:**
* 8 Node Enclosure Box
* 4 Node Enclosure Box
* PCB Tray
* RotorHazard Branded Lid
* RotorHazard Branded Fan Grille
* Three Plain Style Fan Grilles

## **Parts Needed:**
**XT60 connector** to power timer by lipo (Slot for securing zip tie provided, but I recommend a dab of hot glue to really hold it)
http://tiny.cc/12ri8y

**JST connector** for WS2812b LED panel output from Raspberry Pi pins 19-GPIO10,20-GND (Slot for securing zip tie provided, but I recommend a dab of hot glue to really hold it)
http://tiny.cc/e7ri8y

**5.5mm 3 pin DC Jack** for POE
http://tiny.cc/wbsi8y [Wiring Diagram](Images/WireBarrelJack.png)

**POE injector/adapter** (optional)
http://tiny.cc/idsi8y

**2 x 5V 3cm cooling fans**
http://tiny.cc/rsti8y

**Voltage Meter**
http://tiny.cc/o7ti8y
(Secured by two M2 fasteners. Or a couple of dabs of hot glue)

**4 x countersunk M3x20 Machine Screw** To fasten lid
http://tinyurl.com/y3g2hqaf

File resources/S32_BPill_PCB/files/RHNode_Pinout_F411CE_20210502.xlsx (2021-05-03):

S32_BPill Pinout for RHNode
Pins are numbered in standard CCW DIP fashion starting with Pin 1 at Vbat
DIP Pin Number | Standard Designator | F411CE Module | Pins to Pi | Pins to Modules | Pins to Other | Notes | Available Pins
1 | Vbat | VB |  |  | RTC_BAT | Use if internal RTC is desired
2 | PC_13 | PC13 |  |  | LED1 | On-board LED
3 | PC_14 | PC14 |  |  | OSC32_IN | Connected to RTC Crystal
4 | PC_15 | PC15 |  |  | OSC32_OUT | Connected to RTC Crystal
5 | PA_0 | R | Alt - Pill_Reset | RSSI_0 |  | A/D Input
6 | PA_1 | A0 |  | RSSI_1 |  | A/D Input
7 | PA_2 | A1 |  | RSSI_2 |  | A/D Input
8 | PA_3 | A2 |  | RSSI_3 |  | A/D Input
9 | PA_4 | A3 |  | RSSI_4 |  | A/D Input
10 | PA_5 | A4 |  | RSSI_5 |  | A/D Input
11 | PA_6 | A5 |  | RSSI_6 |  | A/D Input
12 | PA_7 | A6 |  | RSSI_7 |  | A/D Input
13 | PB_0 | A7 | GPIO24 |  |  | (Signal from RPi)
14 | PB_1 | B0 |  |  | ADC1_9 | Battery Monitor (resistor divider)
15 | PB_10 | B1 |  | Alt - RSSI_0 | I2C2_SCL | I2C Interface for other peripherals
16 | PB_11 | B2 |  |  | I2C2_SDA | I2C Interface for other peripherals
17 | RESET | B10 | Pill_Reset |  |  | From digital output on Pi
18 | +3.3V | 3V3
19 | GND | GND | GND
20 | GND | 5V |  |  |  | Do not connect!
21 | PB_12 | B12 |  | CH2_4
22 | PB_13 | B13 |  | CH2_5
23 | PB_14 | B14 |  | CH2_6
24 | PB_15 | B15 |  | CH2_7
25 | PA_8 | A8 |  |  | PA_8_OUT | Direct Drive Buzzer, 5V Tolerant
26 | PA_9 | A9 | Serial1_Tx |  |  | Goes to Serial_Rx on Pi
27 | PA_10 | A10 | Serial1_Rx |  |  | Goes to Serial_Tx on Pi
28 | PA_11 | A11 |  |  | USB_DM | Connected to Micro USB Connector
29 | PA_12 | A12 |  |  | USB_DP | Connected to Micro USB Connector
30 | PA_15 | A15 |  |  | AUX_LED | Direct Drive External LED
31 | PB_3 | B3 |  | CH1_All
32 | PB_4 | B4 |  | CH3_All
33 | PB_5 | B5 |  |  | SPI1_MOSI | LED_STRIP
34 | PB_6 | B6 |  | CH2_0
35 | PB_7 | B7 |  | CH2_1
36 | PB_8 | B8 |  | CH2_2
37 | PB_9 | B9 |  | CH2_3
38 | +5V | 5V | +5V
39 | GND | GND | GND
40 | +3.3V | 3V3
 | (Denotes Fixed Function) |  | Boot0 |  |  | From digital output on Pi (Hold high on reset for bootloader)
 |  |  | (Boot will have to be strapped from the top header on Blue Pill. Connection is optional but recommended for debugging.) | On the 5808 Modules: CH1=SPI_Data CH2=SPI_LE CH3=SPI_CLK

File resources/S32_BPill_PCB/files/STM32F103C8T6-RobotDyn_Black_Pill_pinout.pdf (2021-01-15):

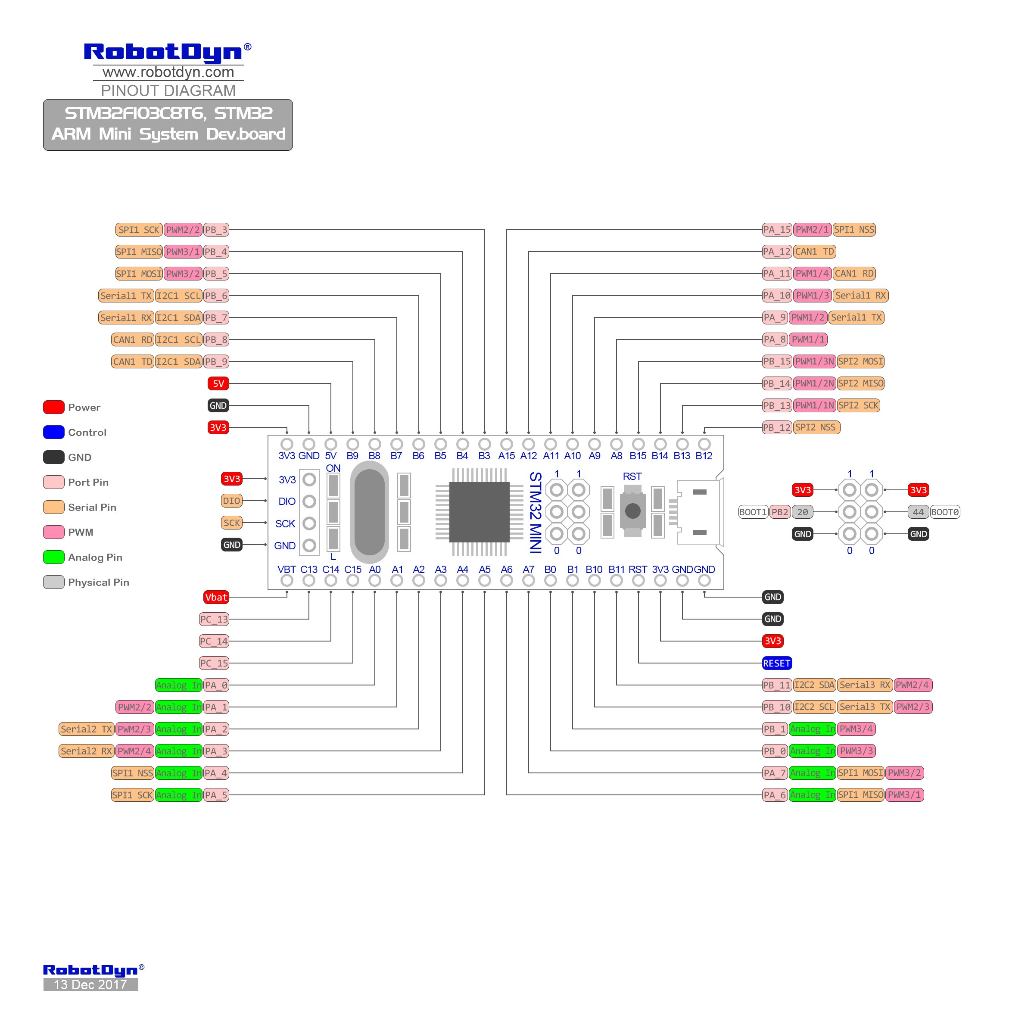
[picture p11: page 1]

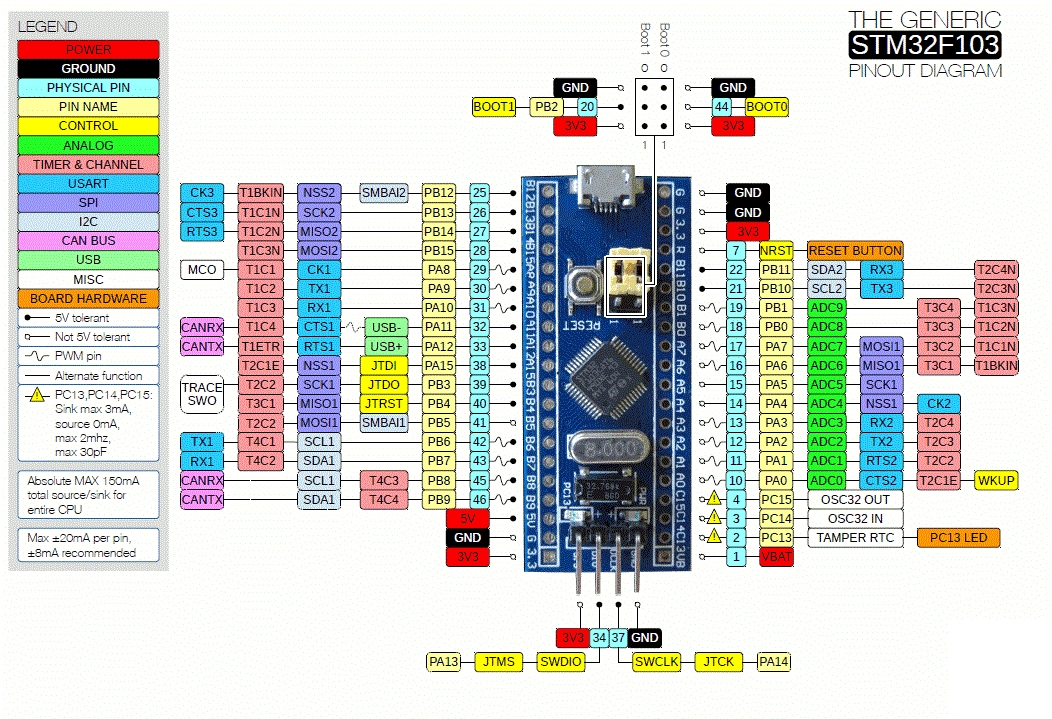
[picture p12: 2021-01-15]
resources/S32_BPill_PCB/files/GenericBluePillPinout.jpg

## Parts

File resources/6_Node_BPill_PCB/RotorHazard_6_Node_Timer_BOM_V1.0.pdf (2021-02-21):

Item Build
Level
Designator | Qty | Part Number | Alternatives | Mouser Ref | Banggood Ref
Optional? | Notes | Link
1 | PCB | U5 | 1 | DS3231SN#T&R

DS3231S#T&R, DS3231SN#,
DS3231S# | 700-DS3231SN#T&R- | -

Yes, fit if you want the real time clock (RTC)

DS3231S is rated for 0 to 70°C,
DS3231SN is rated for -40 to 85°C | https://www.mouser.co.uk/ProductDetail/700-DS3231SN#T&R-
2 | PCB | BZ1 | 1 | CMI-1295-0585T

Any 12mm x 9.5mm 5V
Buzzer | 490-CMI-1295-0585T | - | Yes, used for low voltage alarm | https://www.mouser.co.uk/ProductDetail/490-CMI-1295-0585T
3 | PCB | P12 | 1 | SSW-120-01-T-D

Any 2.54mm 20x2 8.51mm
tall header, single strips also
work | 200-SSW12001TD | - | No | https://www.mouser.co.uk/ProductDetail/200-SSW12001TD
4 | PCB | BT1 | 1

Keystone Electronics
1069 | - | 534-1069 | -

Yes, fit if you want the real time clock
(RTC) | https://www.mouser.co.uk/ProductDetail/534-1069
5 | PCB | C1,C2 | 2 | C0805C104KMRECAUTO

Any 0805 X7R 100nF
capacitor | 80-C0805C104KMRECAUT | -

Yes, these are decoupling capacitors
for INA219 and DS3231. | https://www.mouser.co.uk/ProductDetail/ 80-C0805C104KMRECAUT
6 | PCB | D1,D3 | 2 | 150080VS75000 | Any 0805 LED | 710-150080VS75000 | - | Yes, only fit if you want the onboard
| | | | | | | | power and status LED's

These are driven by 3.3V so check
forward volt drop if using blue or
white LED's and adjust 220r resistor
accordingly | https://www.mouser.co.uk/ProductDetail/710-150080VS75000
7 | PCB | P1 | 1 | XT60 Male | Wire manually to the pad | - | 45394 | No | https://www.banggood.com/search/45394.html
8 | PCB | P2,P3,P16,P17,P18 | 5 | Not required | - | Not required | - | Yes, you can direct solder if required | https://www.mouser.co.uk/ProductDetail/Not required
9 | PCB | P4 | 1 | 3 pin JST SM Female | - | 485-1663 | - | Yes, only needed if you want to use
| | | | | | | | LED rope | https://www.mouser.co.uk/ProductDetail/485-1663
10 | PCB | P5,P14,P15 | 3 | Not required | - | Not required | - | Yes, you can direct solder if required | https://www.mouser.co.uk/ProductDetail/Not required
11 | PCB | P11 | 1 | Not required | - | Not required | - | Yes, you can direct solder if required | https://www.mouser.co.uk/ProductDetail/Not required
12 | PCB | Q1,Q2 | 2 | IRLML6344TRPBF

Any GSD SOT-23 N channel

MOSFET | 942-IRLML6344TRPBF | - | Yes, 1 is used for optional switched
| | | buzzer, the other is used for optional
| | | fan enable control | Make sure if you use an alternative
| | | | the gate, source and drain pins match
| | | | the suggested one | https://www.mouser.co.uk/ProductDetail/942-IRLML6344TRPBF
13 | PCB | R1 | 1 | TLRP3A30WR100FTE

Any 2512 0.1 ohm 1% 3W

resistor | 279-TLRP3A30WR100FTE | - | Yes, only fit if you wish to use the
| | | current reference | | https://www.mouser.co.uk/ProductDetail/279-TLRP3A30WR100FTE
14 | PCB | R2,R7,R8,R9,R11,R12,R13 | 7 | CR0805-JW-104ELF

Any 0805 100k 5% (or better)
resistor | 652-CR0805JW-104ELF | - | No | Buy a few extra in case you drop some | https://www.mouser.co.uk/ProductDetail/652-CR0805JW-104ELF
15 | PCB | R3,R4,R5,R10,R14 | 5 | CR0805-JW-103ELF

Any 0805 10k 5% (or better)
resistor | 652-CR0805-JW-103ELF | - | No | Buy a few extra in case you drop some | https://www.mouser.co.uk/ProductDetail/652-CR0805-JW-103ELF
16 | PCB | R6,R29 | 2 | CR0805-JW-221ELF

Any 0805 220r 5% (or better)

resistor | 652-CR0805-JW-221ELF | - | Yes, only fit if you want the onboard
| | | power and status LED's | Buy a few extra in case you drop some | https://www.mouser.co.uk/ProductDetail/652-CR0805-JW-221ELF
17 | PCB | RX1,RX2,RX3,RX4,RX5,RX6 | 6 | RX5808

IDC-RF variant may be
cheaper on banggood | - | 84775
| | | Yes, 1 of these is required for each
| | | node you wish to fit | | https://www.banggood.com/search/84775.html
18 | PCB | U1 | 1 | INA219AIDR

INA219AID, INA219BID,

INA219BIDR | 595-INA219AIDR | - | Yes, only fit if you wish to use the
| | | current reference | The INA219B is more accurate than
| | | | the A variant | https://www.mouser.co.uk/ProductDetail/595-INA219AIDR
19 | PCB | U2,U3,U4 | 3 | MP1584 | - | 713-106990005 | - | Yes, 1 of these is optional and only
| | | | | | | | used for RGB LED's

Mouser variant only claims up to 18V
input voltage, variants up to 28V exsist
on eBay and are also cheaper, make
sure you get the board and not a
single IC | https://www.mouser.co.uk/ProductDetail/713-106990005
20 | PCB | U2,U3,U4 | 1 | 22-28-4301 | Any 2.54mm header | 538-22-28-4301 | - | No | https://www.mouser.co.uk/ProductDetail/538-22-28-4301
21 | PCB | U6 | 1 | STM32F103C8T6 | - | - | 1668936 | No | https://www.banggood.com/search/1668936.html
22 | PCB | BT1 | 1 | CR1632 | CR1620, CR1616 | - | - | Yes, fit if you want the real time clock
| | | | | | | | (RTC)

CR1632 (140mAh) will last the longests. CR1620 (75mAh), CR1616 (50mAh)
23 | PCB | PCB | 1 | From Github | - | - | - | No | https://www.pcbway.com/project/shareproject/RotorHazard_6_Node_STM32_Lap_Timer.html
24 | Assembly | 1 | RASPBERRYPI_3B+ | Raspberry Pi 4 | - | 1041862 | No | https://www.banggood.com/search/1041862.html
25 | Assembly | | 1 | 8GB + Micro SD card | Any micro SD card between
| | | | | 8GB and 64GB | 467-SDSDQAF3-008G-I | - | No | https://www.mouser.co.uk/ProductDetail/467-SDSDQAF3-008G-I
26 | Assembly | 1 | Raspberry Pi heat syncs | - | - | 1047433 | Yes, either use this or the fans | https://www.banggood.com/search/1047433.html
27 | Assembly | 1 | LCD Voltage Screen | - | - | 1530256 | Yes, only needed if you want to have
| | | | | | | a voltage LED on the case | https://www.banggood.com/search/1530256.html
28 | Assembly | 6 | RX5808 Heat Syncs | Anything up to 24x20x6.5mm | - | 1593902 | Yes, either use these or the fans

The part linked in a 5 pack from
banggood | https://www.banggood.com/search/1593902.html
29 | Assembly | 1 | Thermal Glue | - | - | Yes, either use this or the fans | used to secure the RX5808 heat syncs

30 | Assembly | 11 | M3 8mm Screw | Longer screws may be ok too

- No
31 | Assembly | 4 | M2.5 Countersunk 10mm
| | | screw | Longer screws may be ok too

- No
32 | Assembly | 2 | M2 5mm screw | Longer screws may be ok too

Yes, only needed if the voltage LCD is fitted

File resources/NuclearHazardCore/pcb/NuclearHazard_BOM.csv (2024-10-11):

ID | Name | Designator | Footprint | Quantity | Manufacturer Part | Manufacturer | Supplier | Supplier Part | Price
1 | 100mΩ | RI1 | RES-SMD_L3.2-W1.6_SY1206 | 1 | HoJLR1206-1W-100mR-1% | Milliohm(毫欧) | LCSC | C2903496 | 0.078
2 | INA219AIDCNR | U17 | SOT-23-8_L3.0-W1.7-P0.65-LS2.8-BR | 1 | INA219AIDCNR | TI(德州仪器) | LCSC | C87469 | 0.652
3 | ED12BGFBK | U6,U11,U9,U12 | CONN-TH_12P-P2.54_WINGTAT_ED12BGFBK | 4 | ED12BGFBK | WingTAT(格林柏) | LCSC | C5173290 | 0.369
4 | PZ254V-11-02P | H1 | HDR-TH_2P-P2.54-V-M | 1 | PZ254V-11-02P | XFCN(兴飞) | LCSC | C492401 | 0.013
5 | red | LED2,LED5 | LED0805-R-RD | 2 | NCD0805R1 | 国星光电 | LCSC | C84256 | 0.012
6 | green | LED3 | LED0805-R-RD | 1 | KT-0805G | KENTO | LCSC | C2297 | 0.01
7 | yellow | LED4 | LED0805-R-RD | 1 | KT-0805黄灯 | KENTO | LCSC | C2296 | 0.013
8 | 1K | R4,R5,R1,R2,R3,R29 | R0402 | 6 | 0402WGF1001TCE | UniOhm | LCSC | C11702 | 0.001
9 | XL-1606UGC | LED1 | LED-SMD_L1.7-W1.1-R-RD_GREEN | 1 | XL-1606UGC | XINGLIGHT(成兴光) | LCSC | C965863 | 0.012
10 | 10kΩ | RPCB1,R28,R30,R7,R10,R17 | R0402 | 6 | 0402WGF1002TCE | UniOhm | LCSC | C25744 | 0.001
11 | GT-TCB73B-H048-L1 | SW1 | SW-TH_G-SWITCH_GT-TCB73B-H048-L1 | 1 | GT-TCB73B-H048-L1 | G-Switch(品赞) | LCSC | C2890354 | 0.05
12 | 10uF | C1,C4,C10 | C1206 | 3 | CL31A106KBHNNNE | SAMSUNG | LCSC | C13585 | 0.032
13 | 220uF | C3,C55 | CAP-SMD_L7.3-W4.3-FD | 2 | 10TPE220MIL | PANASONIC(松下) | LCSC | C347538 | 1.438
14 | XH-3AW_C2908612 | CN4 | CONN-TH_3P-P2.54_HCTL_XH-3AW | 1 | XH-3AW | HCTL(华灿天禄) | LCSC | C2908612 | 0.017
15 | HX25003-2A | CN2 | CONN-TH_2P-P2.50_HX25003-2A | 1 | HX25003-2A | HX(红星) | LCSC | C442299 | 0.012
16 | TMB12A03 | BUZZER1 | BUZ-TH_BD12.0-P7.60-D0.6-FD | 1 | TMB12A03 | 华能 | LCSC | C96222 | 0.182
17 | 100nF | C16,CS24,CS36,CS48 | C0402 | 4 | CL05B104KB54PNC | Samsung Electro-Mechanics | LCSC | C307331 | 0.005
18 | 100kΩ | RB1,RB0,RR1,RR2,RR3,RR4,RR5,RR6,RR7,RR8 | R0402 | 10 | 0402WGF1003TCE | UniOhm | LCSC | C25741 | 0.001
19 | STM32F103C8T6 | U8 | LQFP-48_L7.0-W7.0-P0.50-LS9.0-BL | 1 | STM32F103C8T6 | ST(意法半导体) | LCSC | C8734 | 1.14
20 | XT60PW-M | CN1 | CONN-TH_XT60PW-M | 1 | XT60PW-M | AMASS(艾迈斯) | LCSC | C98732 | 0.488
21 | 2.54-2*20 | U10 | HDR-TH_40P-P2.54-V-F-R2-C20-S2.54 | 1 | 2.54-2*20 | ZHOURI(洲日) | LCSC | C2977589 | 0.203
22 | 4.7uF | CS | C0402 | 1 | CL05A475MP5NRNC | SAMSUNG(三星) | LCSC | C23733 | 0.005
23 | AO3400A | Q1 | SOT-23-3_L2.9-W1.6-P1.90-LS2.8-BR | 1 | AO3400A | AOS | LCSC | C20917 | 0.071
24 | 1uF | CS91 | C0402 | 1 | CL05A105KA5NQNC | SAMSUNG(三星) | LCSC | C52923 | 0.003
25 | 10nF | CS92 | C0402 | 1 | CL05B103KB5NNNC | SAMSUNG(三星) | LCSC | C15195 | 0.001
26 | 8MHz | XST1 | OSC-SMD_3P-L3.2-W1.3-P1.2-L | 1 | CSTCE8M00G52-R0 | MuRata | LCSC | C22549 | 0.205
27 | SS34_C8678 | D1,D3 | DO-214AC_L4.3-W2.7-LS5.3-RD | 2 | SS34 | MDD | LCSC | C8678 | 0.025
28 | 180kΩ | R19 | R0603 | 1 | 0603WAF1803T5E | UniOhm | LCSC | C22827 | 0.001
29 | 10nF | C5,C9 | C0402 | 2 | CL05B103KB5NNNC | SAMSUNG | LCSC | C15195 | 0.001
30 | 68uH | L1,L5 | IND-SMD_L11.5-W10.0_104CDMCCDS | 2 | YSPI1050-680M | YJYCOIN | LCSC | C497902 | 0.402
31 | 15kΩ | R9 | R0402 | 1 | 0402WGF1502TCE | UniOhm | LCSC | C25756 | 0.001
32 | 3.3kΩ | R18 | R0402 | 1 | 0402WGF3301TCE | UniOhm | LCSC | C25890 | 0.001
33 | TPS5430DDAR | U1,U4 | SOIC-8_L5.0-W4.0-P1.27-LS6.0-BL-EP2.0 | 2 | TPS5430DDAR | TI(德州仪器) | LCSC | C9864 | 0.266

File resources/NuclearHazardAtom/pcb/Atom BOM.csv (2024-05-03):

ID | Name | Designator | Footprint | Quantity | Manufacturer Part | Manufacturer | Supplier | Supplier Part | Price
1 | 3000Hz | BUZZER2 | BUZ-SMD_L9.6-W9.6-LS10.0-R | 1 | FUET-9650B-5V | FUET(福声科技) | LCSC | C391033 | 0.592
2 | 10uF | C1,C2 | C1206 | 2 | CL31A106KBHNNNE | SAMSUNG | LCSC | C13585 | 0.031
3 | 10nF | C6 | C0402 | 1 | CL05B103KB5NNNC | SAMSUNG | LCSC | C15195 | 0.001
4 | 100nF | C16,CS24,CS36,CS48 | C0402 | 4 | CL05B104KB54PNC | Samsung Electro-Mechanics | LCSC | C307331 | 0.005
5 | 220uF | C55 | CAP-SMD_L7.3-W4.3-FD | 1 | 10TPE220MIL | PANASONIC(松下) | LCSC | C347538 | 1.371
6 | XT60PW-M | CN1 | CONN-TH_XT60PW-M | 1 | XT60PW-M | AMASS(艾迈斯) | LCSC | C98732
7 | HX25003-2A | CN3 | CONN-TH_2P-P2.50_HX25003-2A | 1 | HX25003-2A | HX(红星) | LCSC | C442299 | 0.011
8 | XH-3AW_C2908612 | CN4 | CONN-TH_3P-P2.54_HCTL_XH-3AW | 1 | XH-3AW | HCTL(华灿天禄) | LCSC | C2908612 | 0.015
9 | 4.7uF | CS | C0402 | 1 | CL05A475MP5NRNC | SAMSUNG(三星) | LCSC | C23733 | 0.005
10 | 1uF | CS91 | C0402 | 1 | CL05A105KA5NQNC | SAMSUNG(三星) | LCSC | C52923 | 0.003
11 | 10nF | CS92 | C0402 | 1 | CL05B103KB5NNNC | SAMSUNG(三星) | LCSC | C15195 | 0.001
12 | SS34_C8678 | D2 | DO-214AC_L4.3-W2.7-LS5.3-RD | 1 | SS34 | MDD | LCSC | C8678 | 0.024
13 | 68uH | L2 | IND-SMD_L11.5-W10.0_104CDMCCDS | 1 | YSPI1050-680M | YJYCOIN | LCSC | C497902 | 0.374
14 | KT-0603R | LED1,LED2 | LED0603-RD | 2 | KT-0603R | KENTO | LCSC | C2286 | 0.005
15 | AO3400A | Q1 | SOT-23-3_L2.9-W1.6-P1.90-LS2.8-BR | 1 | AO3400A | AOS | LCSC | C20917 | 0.065
16 | 2.2kΩ | R1 | R0402 | 1 | RC0402JR-072K2L | YAGEO(国巨) | LCSC | C163447 | 0.001
17 | 1K | R3,R4,R29 | R0402 | 3 | 0402WGF1001TCE | UniOhm | LCSC | C11702 | 0.001
18 | 6.8kΩ | R5 | R0402 | 1 | RC0402JR-076K8L | YAGEO(国巨) | LCSC | C137847 | 0.002
19 | 10kΩ | R28,R30,RPCB1 | R0402 | 3 | 0402WGF1002TCE | UniOhm | LCSC | C25744 | 0.001
20 | 100kΩ | RB0,RB1,RR1,RR2,RR3,RR4,RR5,RR6,RR7,RR8 | R0402 | 10 | 0402WGF1003TCE | UniOhm | LCSC | C25741 | 0.001
21 | GT-TCB73B-H048-L1 | SW1 | SW-TH_G-SWITCH_GT-TCB73B-H048-L1 | 1 | GT-TCB73B-H048-L1 | G-Switch(品赞) | LCSC | C2890354 | 0.037
22 | ESP32-WROOM-32UE(16MB) | U1 | WIFI-SMD_ESP32-WROOM-32UE | 1 | ESP32-WROOM-32UE-N16 | ESPRESSIF(乐鑫) | LCSC | C701346 | 3.937
23 | Raspberry Pi Zero W | U3 | PI ZERO | 1 | Pi Zero
24 | TPS5430DDAR | U5 | SOIC-8_L5.0-W4.0-P1.27-LS6.0-BL-EP2.0 | 1 | TPS5430DDAR | TI | LCSC | C9864 | 0.41
25 | RX5808 NO ANT ELECTRICAL CONNECTION SMD | U6,U7 | RX5808 NO ANT ELECTRICAL CONNECTION SMD | 2
26 | STM32F103C8T6 | U8 | LQFP-48_L7.0-W7.0-P0.50-LS9.0-BL | 1 | STM32F103C8T6 | ST(意法半导体) | LCSC | C8734 | 1.159
27 | 2.54-2*20 | U10 | HDR-TH_40P-P2.54-V-F-R2-C20-S2.54 | 1 | 2.54-2*20 | ZHOURI(洲日) | LCSC | C2977589 | 0.22
28 | 8MHz | XST1 | OSC-SMD_3P-L3.2-W1.3-P1.2-L | 1 | CSTCE8M00G52-R0 | MuRata | LCSC | C22549 | 0.209

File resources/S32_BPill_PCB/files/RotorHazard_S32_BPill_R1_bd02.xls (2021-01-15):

Bill of Materials |  |  | Bill of Materials For Project [RotorHazard_S32_BPill_R1.PrjPCB]
Project: |  | RotorHazard_S32_BPill_R1.PrjPCB
Creation Date: | 12/28/2020 | 3:50:35 PM
Footprint | Comment | LibRef | Designator | Description | Quantity
BZ_12mm | TMB12A05 | Buzzer_12mm | BZ1 | TMB12A05 12mmX9.5mm Buzzer (https://www.amazon.com/TMB12A05-Universal-Active-Electromagnetic-Speaker/dp/B07SL2PJ3J) | 1
Cap Radial 100mil | 0.1uF 50V X7R | C320C104K5R5TA7301 | C1, C2 | Multilayer Ceramic Capacitors MLCC - Leaded 50V 0.1uF 10% X7R (https://www.mouser.com/ProductDetail/KEMET/C320C104K5R5TA7301) | 2
Axial 0.4 Diode | MBR100RLG | MBR1100RLG | D1 | Schottky Diodes & Rectifiers 1A 100V (https://www.mouser.com/ProductDetail/ON-Semiconductor/MBR1100RLG) | 1
HDR 1x2_2.54mm | HDR 1X2 | 961102-6804-AR | J1, J3, J5, J6, J9, JP1, JP2 | Headers & Wire Housings 2P STRT 1 ROW GOLD 6.8MM MATING PIN (https://www.mouser.com/ProductDetail/3M-Electronic-Solutions-Division/2302-6121TG) | 7
HDR 1x4_2.54mm | HDR 1X4 | 961104-6804-AR | J2, J8, J10 | Headers & Wire Housings 4P STRT 1 ROW GOLD 6.8MM MATING PIN (https://www.mouser.com/ProductDetail/3M-Electronic-Solutions-Division/961104-6804-AR) | 3
6-PIN SIL VERT SOCKET | 6 PIN SIL VERT SOCKET | M20-7820646 | J4 | Headers & Wire Housings 6 PIN SIL VERTICAL SOCKET TIN *Note 4 (https://www.mouser.com/ProductDetail/Harwin/M20-7820646) | 1
Header_2X20_Vert_Thru | Header_2X20_Vert_Thru | Header_To_Pi_Cable | J7 | Header_2X20_Vert_Thru (https://www.mouser.com/ProductDetail/Molex/70246-4004) | 1
HDR 1x1_2.54mm | HDR 1X1 | HEADER 1X1 | J11, J12, J13, J14 | Single pin header *Note 2 (https://www.amazon.com/Hotop-Pack-Single-Header-Connector/dp/B06XR8CV8P/) | 4
XT30_M | XT30-M | XT30-M | J15 | XT30 connector male pins (https://www.amazon.com/Finware-Upgrade-Female-Connectors-Battery/dp/B074S7NH3H/) | 1
LED_5mm | LED_5mm | LED_5mm | LED1 | 5mm standard leaded red LED (https://www.mouser.com/ProductDetail/Cree-Inc/C503B-RAN-CZ0C0AA1) | 1
Axial 0.4 100 CF | 100 1/4W 5% | CFR-25JR-52-100R | R1 | Carbon Film Resistors - Through Hole 100ohm 1/4W 5% (https://www.mouser.com/ProductDetail/Yageo/CFR-25JR-52-100R?qs=sGAEpiMZZMsPqMdJzcrNwiPCnpFTGbbhYHVmSfLkWwk%3D) | 1
Axial 0.4 100K CF | 100K 1/4W 5% | CFR-25JR-52-100K | R2 | Carbon Film Resistors - Through Hole 100K ohm 1/4W 5% (https://www.mouser.com/ProductDetail/Yageo/CFR-25JR-52-100K) | 1
Axial 0.4 1K CF | 1K 1/4W 5% | CFR-25JT-52-1K | R3 | Carbon Film Resistors - Through Hole 1/4W 1K Ohm 5% (https://www.mouser.com/ProductDetail/Yageo/CFR-25JT-52-1K?qs=KUIzHt%2Fe91mODjNMcON1KQ%3D%3D) | 1
Axial 0.4 10K MF | 10K 1/4W 1% | MFR-25FRF52-10K | R4 | Metal Film Resistors - Through Hole 10K ohm 1/4W 1% (https://www.mouser.com/ProductDetail/Yageo/MFR-25FRF52-10K?qs=sGAEpiMZZMu61qfTUdNhGztMfEiwFKKTpKeEBKehEYg%3D) | 1
Axial 0.4 1K MF | 1K 1/4W 1% | MFR-25FRF52-1K | R5 | Metal Film Resistors - Through Hole 1K ohm 1/4W 1% (https://www.mouser.com/ProductDetail/Yageo/MFR-25FRF52-1K?qs=sGAEpiMZZMu61qfTUdNhGztMfEiwFKKTY1DevuMNI5M%3D) | 1
RES_SIP_10P | 100K 10Pin SIP | 4610X-101-104LF | RA1 | Resistor Networks & Arrays 10pins 100Kohms Bussed (https://www.mouser.com/ProductDetail/Bourns/4610X-101-104LF?qs=sGAEpiMZZMvrmc6UYKmaNWZq5LK2CquH8Ch17mVAQEE%3D) | 1
RH_S32_Node_PCB | RX5808_PCB | RH_S32_Node | U1, U2, U3, U4, U5, U6, U7, U8 | RX5808 module on PCB with right-angle header pins *Note 1 | 8
BME280_PCB | BME280_BRD | BME280 | U9 | BME280 Temperature, Humidity and Pressure Sensor (https://www.amazon.com/Onyehn-Temperature-Humidity-Barometric-Pressure/dp/B07KR24P6P/) | 1
INA219_PCB_RA | INA219_BRD | INA219_BRD | U10 | INA219 Current Sensor/Voltage Monitor (https://www.adafruit.com/product/904) | 1
DIP40_Plus2 | STM32F103XX BPill | STM32F103XX_BPill | U11 | STMF103XX BPill (https://www.amazon.com/HiLetgo-STM32F103C8T6-Minimum-Development-Learning/dp/B07VKSVM21/) | 1
D36V28FX | D36V28F5 | D36V28F5 | U12 | Pololu D36V28F5 DC/DC Converter (https://www.pololu.com/product/3782) | 1
D24V22FX | D24V22F3 | D24V22F3 | U13 | Pololu D24V22F3 DC/DC Converter (https://www.pololu.com/product/2857) | 1
DS3231_Breakout | DS3231_BBRD | DS3231_Breakout | U14 | ADAFruit DS3231 Breakout Board *Note 3 (https://www.adafruit.com/product/3013) | 1
Pi_RTC | DS3231_Pi_RTC | DS3231_Pi_RTC | U15 | ADAFruit DS3231 PiRTC *Note 3 (https://www.adafruit.com/product/4282) | 1
Parts for Each Node
HDR 1X9 2.54mm RA | HDR 1X9 RA | 649-1012937990904BLF | J1 | 9-Pin RA Header Thru-Hole *Note 5 (https://www.mouser.com/ProductDetail/Amphenol-FCI/10129379-909004BLF?qs=0lQeLiL1qyZfaqCOsdhrCw%3D%3D) | 1
RX5808_MULTI | RX5808 | RX5808_MULTI | U1 | RX5808 Module *Note 6 (https://www.banggood.com/Boscam-5_8G-Wireless-Audio-Video-FPV-Receiver-Receiving-Module-RX5808-for-RC-Drone-FPV-Racing-p-84775.html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) | 1
Notes
1) The number of nodes is up to the user and should be automatically detected. High-quality low-profile sockets made from the strips linked here are recommended. (https://www.mouser.com/ProductDetail/Mill-Max/801-93-036-10-012000?qs=WZRMhwwaLl%2F7W%252BkSMqBETQ%3D%3D) | https://www.mouser.com/ProductDetail/Mill-Max/801-93-036-10-012000?qs=WZRMhwwaLl%2F7W%252BkSMqBETQ%3D%3D | 3) The DS3231 RTCs are optional, but if installed only one should be used at a time. |  | 5) When used with the low-profile sockets the pins should be cut to a length of 3.5mm-4.0mm as measured from the edge of the node PCB.
https://www.mouser.com/ProductDetail/Mill-Max/801-93-036-10-012000?qs=WZRMhwwaLl%2F7W%252BkSMqBETQ%3D%3D | https://www.mouser.com/ProductDetail/Mill-Max/801-93-036-10-012000?qs=WZRMhwwaLl%2F7W%252BkSMqBETQ%3D%3D
2) There are two more single-pin headers that are part of the STM32 CPU component. The one for BOOT0 is required to enable firmware upload. All of the rest are optional. If used these should probably just be separated from the longer breakable strips linked above. |  | 4) Sockets are also recommended for the STM32 CPU and BME280. The best source is probably to get a kit similar to the one linked here from Amazon which will provide enough for several timers. (https://www.amazon.com/Glarks-Straight-Connector-Assortment-Prototype/dp/B076GZXW3Z/) | https://www.amazon.com/Glarks-Straight-Connector-Assortment-Prototype/dp/B076GZXW3Z/ | 6) The "Blue Pill" boards are available from a variety of places and generally have clone versions of the CPU. There is a higher-quality board available from RobotDyn (linked below) but it is often out-of-stock.
 |  | https://www.amazon.com/Glarks-Straight-Connector-Assortment-Prototype/dp/B076GZXW3Z/ | https://www.amazon.com/Glarks-Straight-Connector-Assortment-Prototype/dp/B076GZXW3Z/
 |  | https://www.amazon.com/Glarks-Straight-Connector-Assortment-Prototype/dp/B076GZXW3Z/ | https://www.amazon.com/Glarks-Straight-Connector-Assortment-Prototype/dp/B076GZXW3Z/
 |  | https://www.amazon.com/Glarks-Straight-Connector-Assortment-Prototype/dp/B076GZXW3Z/ | https://www.amazon.com/Glarks-Straight-Connector-Assortment-Prototype/dp/B076GZXW3Z/ | Link to RobotDyn CPU Boards (https://robotdyn.com/stm32f103-stm32-arm-mini-system-dev-board-stm-firmware.html)

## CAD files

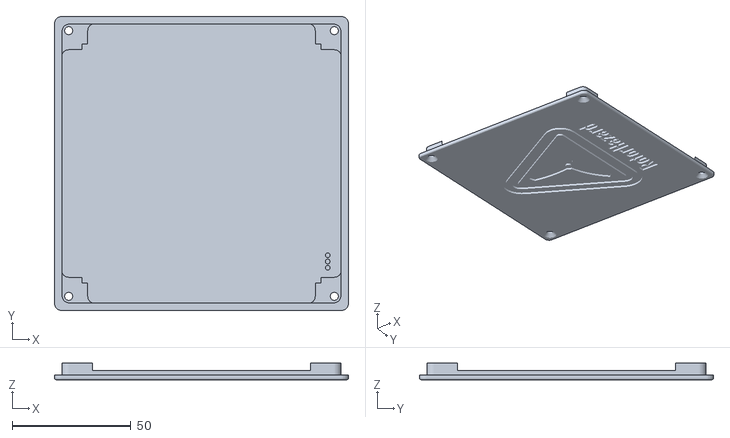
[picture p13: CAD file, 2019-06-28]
resources/enclosure/Lid RotorHazard.stl
124.0 x 124.0 x 7.00

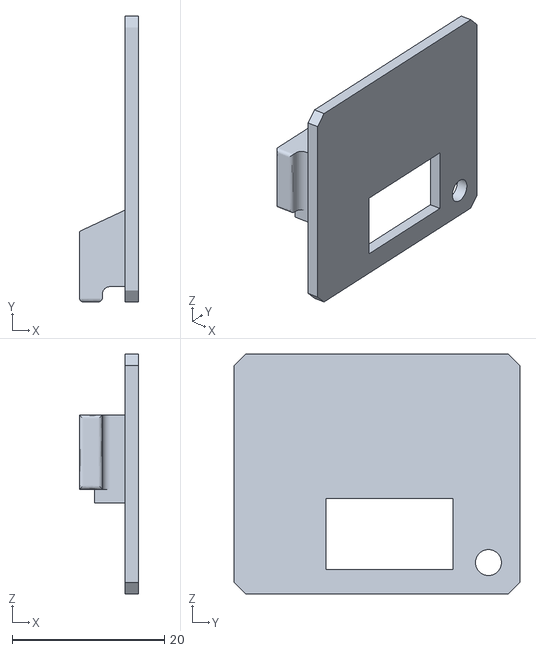
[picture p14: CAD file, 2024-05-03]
resources/NuclearHazardAtom/stl/Atom Lid.stl
7.75 x 37.5 x 31.5

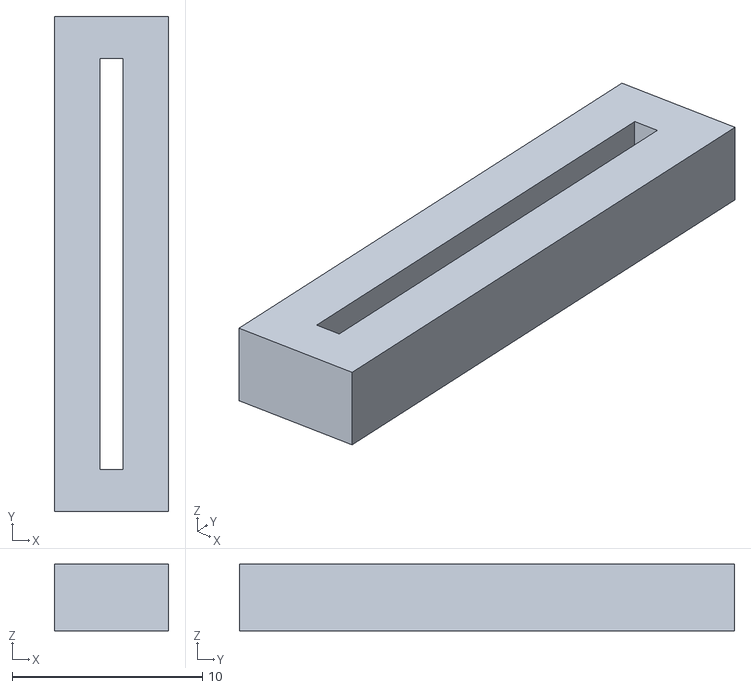
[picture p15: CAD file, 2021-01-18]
resources/S32_BPill_PCB/files/RH_S32_BPill_nodeTrimJig.stl
6.00 x 26.0 x 3.50

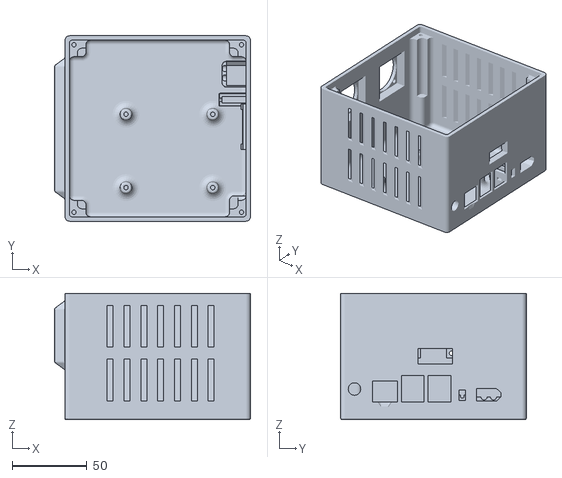
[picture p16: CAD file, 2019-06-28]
resources/enclosure/Box Eight Node.stl
131.0 x 124.0 x 84.5

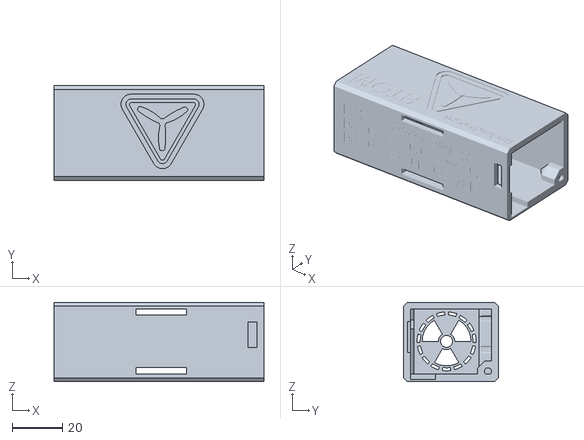
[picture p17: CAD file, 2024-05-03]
resources/NuclearHazardAtom/stl/Atom Case.stl
83.2 x 37.5 x 31.5

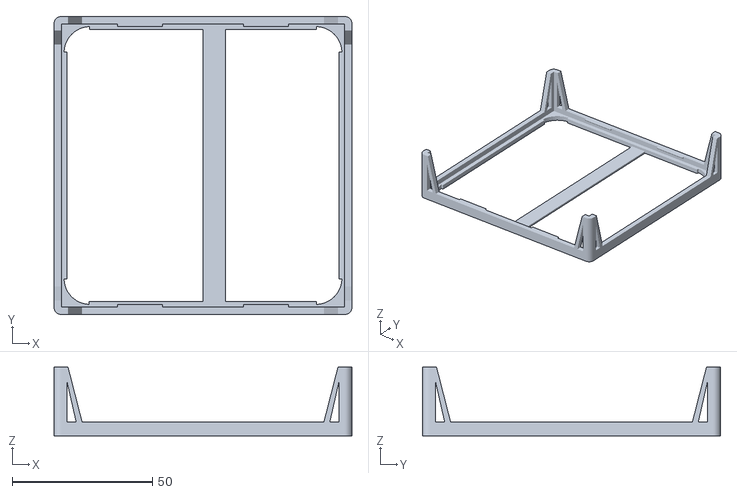
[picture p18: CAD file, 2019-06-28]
resources/enclosure/PCB Tray.stl
106.2 x 106.2 x 24.5

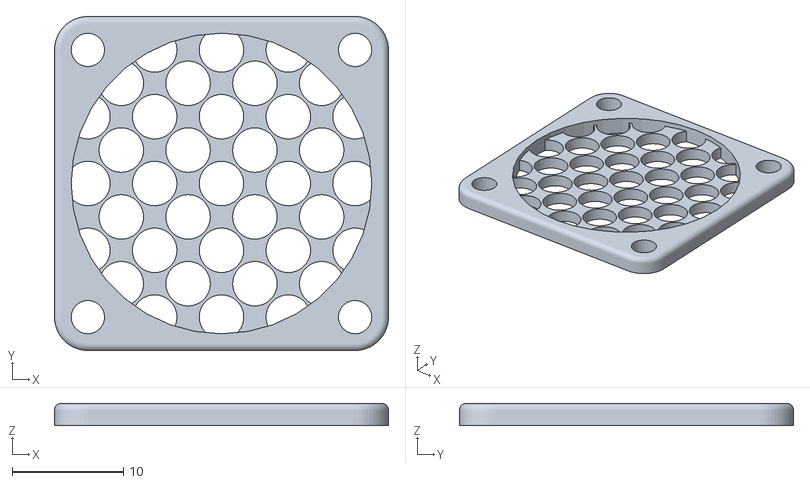
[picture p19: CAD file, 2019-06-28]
resources/enclosure/Grille Circles.stl
30.0 x 30.0 x 2.00

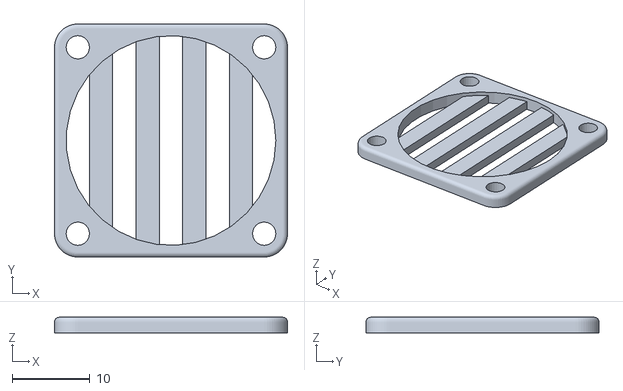
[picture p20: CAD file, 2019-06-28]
resources/enclosure/Grille Slatted.stl
30.0 x 30.0 x 2.00

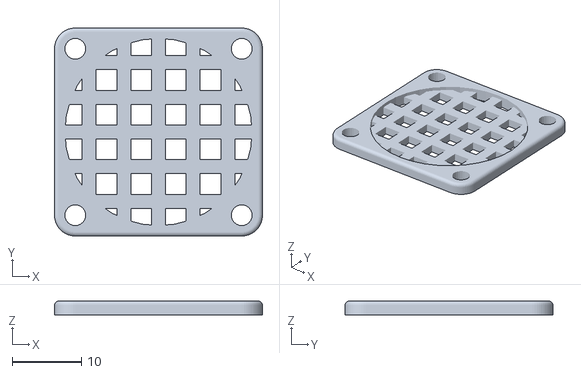
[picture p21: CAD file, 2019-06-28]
resources/enclosure/Grille Squares.stl
30.0 x 30.0 x 2.00

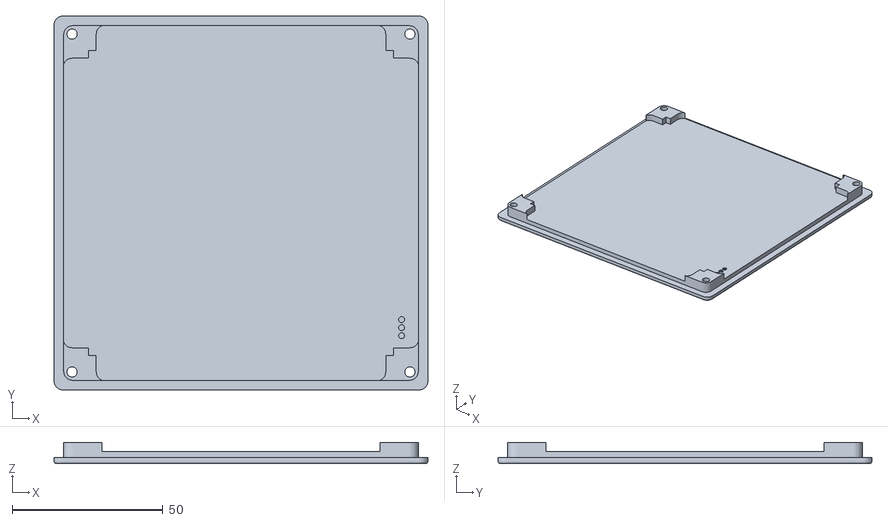
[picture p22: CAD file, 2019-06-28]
resources/enclosure/Lid Plain.stl
124.0 x 124.0 x 7.00

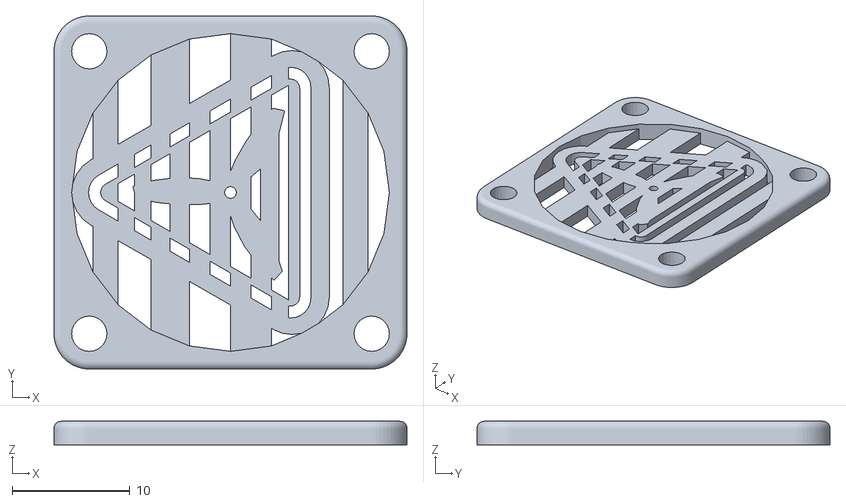
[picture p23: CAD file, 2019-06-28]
resources/enclosure/Grille RotorHazard.stl
30.0 x 30.0 x 2.00

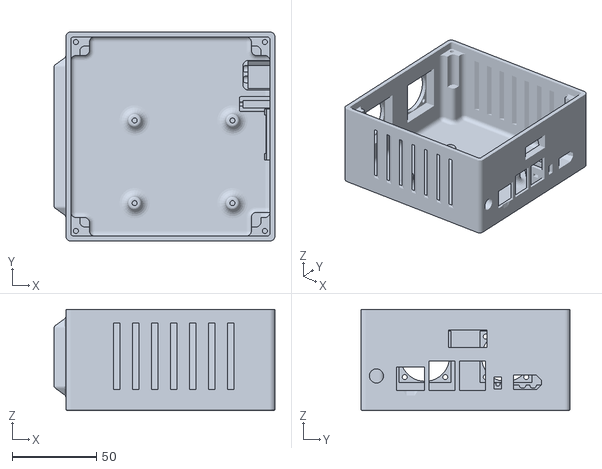
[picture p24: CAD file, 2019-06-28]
resources/enclosure/Box Four Node.stl
131.0 x 124.0 x 59.9

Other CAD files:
resources/S32_BPill_PCB/files/RH_S32_BPill_nodeTrimJig.blend

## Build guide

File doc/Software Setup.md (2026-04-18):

# Software Setup Instructions

- [Introduction](#introduction)
- [Install RotorHazard on a Raspberry Pi](#install-rotorhazard-on-a-raspberry-pi)
- [The Data Directory](#the-data-directory)
- [Running the RotorHazard Server](#running-the-rotorhazard-server)
- [RotorHazard Node Code](#rotorhazard-node-code)
- [Enable Port Forwarding](#enable-port-forwarding)
- [Optional Components](#optional-components)
- [Updating an Existing Installation](#updating-an-existing-installation)
- [Other Operating Systems](#other-operating-systems)
- [Viewing Database Files](#viewing-database-files)
- [RotorHazard Portable](#rotorhazard-portable)
- [Logging](#logging)

## Introduction

The central software component of the RotorHazard system is its server, written in Python, which operates its functions and serves up web pages to browsers. In a standard setup, the server is run on a [Raspberry Pi](https://www.raspberrypi.org). (It is also possible to run RotorHazard on other types of hardware -- see the [Other Operating Systems](#otheros) section below.)

Note: If RotorHazard is already installed, see the [Updating an existing installation](#update) section below.

Once the server is setup and running, see the RotorHazard Race Timer [User Guide](User%20Guide.md) for further instructions and setup tips.

## Install RotorHazard on a Raspberry Pi

### 1. Install the Raspberry Pi Operating System

Note: Many of the setup commands below require that the Rasperry Pi has internet access.

Install the Raspberry Pi OS, following the official instructions: https://www.raspberrypi.org/help

The standard-recommended setup is to use a Raspberry Pi 3, Pi 4 or Pi 5 board, install the [Raspberry Pi OS](https://www.raspberrypi.org/software/operating-systems/#raspberry-pi-os-32-bit) (Desktop), and configure it with a user named "pi".

Tip: Any time you intend to use a monitor (via HDMI) with the Raspberry Pi, connect it before powering up the Pi. Connecting the monitor after power up tends to not work (blank screen).

### 2. Configure Interface Options

(The options may be configured using step 2a or 2b below.)

#### 2a. Configure interface options using the desktop
If Raspberry Pi OS with Desktop was installed, the interface options may be configured via "Preferences" | "Raspberry Pi Configuration" | "Interfaces":
* Enable SSH, SPI, I2C, and 'Serial Port'
* Disable 'Serial Console'
* For remote access to the desktop (using a program like [RealVNC viewer](https://www.realvnc.com/en/connect/download/viewer)), enable VNC

#### 2b. Configure interface options using a terminal window
If the Pi OS Desktop is not available, the interface options may be configured using the following command:
```
sudo raspi-config
```
* Select 'Interface Options' and enable: SSH, SPI, and I2C
* Select 'Interface Options' | 'Serial Port', and configure:
  * "login shell accessible serial": No
  * "serial port hardware enabled": Yes

### 3. Apply Changes to the 'boot' _config.txt_ file
Open a terminal window and enter:
```
if [ -f "/boot/firmware/config.txt" ]; then sudo nano /boot/firmware/config.txt; else sudo nano /boot/config.txt; fi
```
Add the following lines to the end of the file:
```
dtparam=i2c_baudrate=75000
dtoverlay=miniuart-bt
```
If the Raspberry Pi in use is a Pi 3 model or older (not a Pi 4 or 5) then add this line:
```
core_freq=250
```
If your hardware is the S32_BPill setup with [shutdown button](Shutdown%20Button.md) and AUX LED then add these lines:
```
dtoverlay=act-led,gpio=24
dtparam=act_led_trigger=heartbeat
```
If the Raspberry Pi in use is a Pi 4 model or older (not a Pi 5) and your hardware is the S32_BPill setup with [shutdown button](Shutdown%20Button.md) then add this line:
```
dtoverlay=gpio-shutdown,gpio_pin=18,debounce=5000
```
If the Raspberry Pi in use is a Pi 5 model then add these lines:
```
dtoverlay=uart0-pi5
dtoverlay=i2c1-pi5
```
Save and exit the editor (CTRL-X, Y, ENTER)

*Notes:*

On newer versions of the Raspberry Pi OS, the boot-config file location is "/boot/firmware/config.txt". On older versions it is "/boot/config.txt".

The first line sets the transfer rate on the I2C bus (which is used to communicate with the Arduino node processors).

The "dtoverlay=miniuart-bt" line moves the high performance UART from the Bluetooth device to the GPIO pins, which is needed for setups like the S32_BPill that use the serial port as the communications channel to the nodes.

The "core_freq" line fixes a potential variable clock-rate issue, described [here](https://www.abelectronics.co.uk/kb/article/1089/i2c--smbus-and-raspbian-stretch-linux). If a Raspberry Pi 4 or Pi 5 is being used, the "core_freq" line should be omitted (as per the Raspberry Pi documentation [here](https://www.raspberrypi.org/documentation/configuration/config-txt/overclocking.md)).

For the S32_BPill setup, the "dtoverlay=act-led,gpio=24" and "dtparam=act_led_trigger=heartbeat" lines configure a Raspberry-Pi-heartbeat signal that the BPill processor monitors to track the status of the Pi. The "dtoverlay=gpio-shutdown..." line makes it so the shutdown button still operates if the RotorHazard server is not running.

If the Raspberry Pi 5 is being used, the "dtoverlay=uart0-pi5" and "dtoverlay=i2c1-pi5" lines configure the devices to operate similar to how they do with the Pi 3 & 4. 

### 4. Perform System Update
Using a terminal window, do a system update and upgrade (this can take a few minutes):
```
sudo apt update && sudo apt upgrade
```

### 5. Install Python
Using a terminal window, install Python and the Python drivers for the GPIO:
```
sudo apt install python3-dev python3-venv libffi-dev python3-smbus build-essential python3-pip git scons swig python3-rpi.gpio
```
Enter the following commands to setup the Python virtual environment:
```
cd ~
python -m venv --system-site-packages .venv
```
Configure the user shell to automatically activate the Python virtual environment by entering the command `nano .bashrc` to edit the ".bashrc" file and adding the following lines to the end of the file:
```
VIRTUAL_ENV_DISABLE_PROMPT=1
source ~/.venv/bin/activate
```
Save and exit the editor (CTRL-X, Y, ENTER)

### 6. Reboot System
After the above setup steps are performed, the system should be rebooted by entering the following using a terminal window:
```
sudo reboot
```

### 7. Install the RotorHazard Server

To install the [latest stable release](https://github.com/RotorHazard/RotorHazard/releases/latest), enter the following commands:

```bash
cd ~
wget https://rotorhazard.com/install.sh
sh install.sh
```

To install another version, add the desired version code after `install.sh` - for example:
```bash
sh install.sh v4.3.0-beta.1
```

Note:
* The updates for the RotorHazard server Python dependencies may take a few minutes
* Error messages about "pip's dependency resolver ... Flask-SQLAlchemy not installed" may be safely ignored

### 8. Configuration File
When the RotorHazard server is run for the first time, it will create a `config.json` file in the data directory. **As of RotorHazard 4.3, it is not necessary to hand-edit this file.** All settings can be modified within the frontend user interface. The `config.json` file may still be directly edited to alter the configuration settings, but this must only be done while the RotorHazard server is not running, otherwise the changes will be overwritten. When the server starts up, if it detects that the `config.json` has been updated, it will load the settings and then create a backup copy of the file (with a filename in the form "config_bkp_YYYYMMDD_hhmmss.json").

The contents of the "config.json" file must be in valid JSON format. A validator utility like [JSONLint](https://jsonlint.com/) can be used to check for syntax errors.

----------------------------------------------------------------------------

## The Data Directory

> [!TIP]
> For typical installations, you may skip this section. Your data directory will reside in the "home" folder of the current user, at `~/rh-data`.

It is recommended that users store their data in a separate data directory from the program files. This allows users to upgrade without manually copying files—simply replace the program directory with the new version. Prior to v4.3, RotorHazard would store these files in the program directory. If you start a server that was previously run this way, RotorHazard will offer to attempt a migration for you.

The data directory may contain:

* Event database (`/database.db`)
* Archived events and event database backups
* Configurtaion file (`/config.json`)
* Server logs (`/logs/`)
* A public front-end–accessible directory (`/shared/`)
* User-installed plugins (`/plugins/`) 

You may also wish to store your Python Virtual Environment here, and plugins may store additional files.

### Setting the Data Directory

There are several options to specify your data directory, following an order of priority. Once a selection has been made, the other options are ignored.

#### 1: `--data` command-line arg
If you specify `--data <path>` on the command line when running the server, the location specified with `<path>` will be used.

#### 2: `datapath.ini`
If a `datapath.ini` file exists in the program directory and the location is valid, it will be used. If you ask RotorHazard to continue running in the program directory, it will write this file so the prompt does not reappear. Note that this method prevents some of the benefits of keeping data separate.

#### 3: `~/rh-data`, if it exists
If the `rh-data` directory exists in your operating system home/user directory, it will be used.

#### 4: Implicit run from program directory
If `config.json` exists in the program directory, the program directory will be used. The server will display a prompt on the `settings` page with a choice to migrate to `~/rh-data`.

#### 5: If CWD contains config, use CWD
if the current working directory of the operating system contains a `config.json` file, the current working directory will be used.

#### 6: Creating `~/rh-data`
The server will attempt to create `~/rh-data` and use it.

If the data directory cannot be selected, the server will not start.

----------------------------------------------------------------------------

## Running the RotorHazard Server

The following instructions will start the RotorHazard server on the Raspberry Pi, allowing full control and configuration of the system to run races and save lap times.

### Manual Start

Open a terminal window and enter the following:
```bash
cd ~/RotorHazard/src/server
python server.py
```
The server may be stopped by hitting Ctrl-C

Once the server is running, its web-GUI interface may be accessed in a browser; see the [Connect to the Server](User%20Guide.md#connect-to-the-server) section in the [User Guide](User%20Guide.md) for more information.

If no configuration file exists when the server is started, RotorHazard will prompt the user to confirm an admin username and password the first time the server frontend is accessed. You will need these credentials to access pages reserved for the race director (i.e., the *Settings* and *Run* pages).

### Start on Boot

To configure the system to automatically start the RotorHazard server when booting up:

Create a service file:
```bash
sudo nano /lib/systemd/system/rotorhazard.service
```

Copy and paste the following contents into the file:
```bash
[Unit]
Description=RotorHazard Server
After=multi-user.target

[Service]
User=pi
WorkingDirectory=/home/pi/RotorHazard/src/server
ExecStart=/home/pi/.venv/bin/python server.py

[Install]
WantedBy=multi-user.target
```

*Note*: If the username was configured as something other than "pi" during the Operating System setup, be sure to change the value `pi` in `User`, `WorkingDirectory` and `ExecStart` to match your username.

Save and exit (CTRL-X, Y, ENTER)

Enter the following command to update the service-file permissions:
```
sudo chmod 644 /lib/systemd/system/rotorhazard.service
```

Enter these commands to enable the service:
```
sudo systemctl daemon-reload
sudo systemctl enable rotorhazard.service
```
The service may now be started manually by entering the command `sudo systemctl start rotorhazard`, and should start up automatically when the Raspberry Pi is started up.

### Stopping the Server Service
If the RotorHazard server was started as a service during the boot, it may be stopped with a command like this:
```
sudo systemctl stop rotorhazard
```
To disable the service (so it no longer runs when the system starts up), enter:
```
sudo systemctl disable rotorhazard.service
```
To query the status of the service:
```
sudo systemctl status rotorhazard.service
```
If the service is running then the output will contain `Active: active (running)`. Hit the 'Q' key to exit the status command.

### Shutting Down the System
A system shutdown should always be performed before unplugging the power, either by clicking on the 'Shutdown' button on the 'Settings' page on the web GUI, or by entering the following in a terminal:
```
sudo shutdown now
```
The physical [shutdown button](Shutdown%20Button.md) may also be used on hardware that supports it.

----------------------------------------------------------------------------

## RotorHazard Node Code

The firmware for the RotorHazard nodes will need to be installed (or updated). The nodes can be Arduino based (with an Arduino processor for each node channel), or use the multi-node S32_BPill board (with a single STM32F1 processor running 1-8 channels).

For Arduino-based node boards, see the '[src/node/readme_Arduino.md](../src/node/readme_Arduino.md)' file for more information and instructions for installing the node firmware code.

For the S32_BPill board, the recommended method for installing the currently-released node firmware is to use the `Update Nodes` button (in the 'System' section on the 'Settings' page) on the RotorHazard web GUI.<br>
The "dtoverlay=miniuart-bt" line needs to have been added to the 'boot' _config.txt_ file for the flash-update to succeed (see instructions above).<br>
Note that the flash-update steps described in '[src/node/readme_S32_BPill.md](../src/node/readme_S32_BPill.md)' are for developers who wish to build the S32_BPill node firmware from the source code.

The node-code version may be viewed in the Server Log, and via the "About RotorHazard" item in the drop-down menu.

----------------------------------------------------------------------------

## Enable Port Forwarding
The RotorHazard server defaults to port 5000, as this is necessary for some 3rd party integrations. While you can change the port in the server configuration (`GENERAL > HTTP_PORT`), a better approach is often to forward the web default port of 80 to 5000.

By default, HTTP uses port 80. Other values will require that the port be included as part of the URL entered into client browsers. If other web services are running on the Pi, port 80 may already be in use and reusing it will cause problems. If port 80 is used directly via `HTTP_PORT`, the server may need to be run using the *sudo* command. With the following commands, the server runs on port 5000 but the system sends the traffic from port 80 to it.

```
sudo apt-get install iptables
sudo iptables -A PREROUTING -t nat -p tcp --dport 80 -j REDIRECT --to-ports 5000
sudo iptables -A PREROUTING -t nat -p tcp --dport 8080 -j REDIRECT --to-ports 80
sudo iptables-save
sudo apt-get install iptables-persistent
```
After running these commands, RotorHazard will be available from both ports 80 and 5000. When available by port 80, you may leave the port off when accessing the server, i.e.: `http://127.0.0.1`

Note: The second *iptables* command will forward port 8080 to 80, so services that would normally be available on port 80 will instead be available on port 8080. If port 80 services are not present or if other services are using port 8080, this *iptables* command may be omitted.
<br/>

----------------------------------------------------------------------------

## Optional Components

### Real Time Clock

The installation of a real-time clock module allows the RotorHazard timer to maintain the correct date and time even when an internet connection is not available. See '[doc/Real Time Clock.md](Real%20Time%20Clock.md)' for more information.

### WS2812b LED Support

Support for WS2812b LED strips (and panels) is provided by the Python library '[rpi-ws281x](https://github.com/rpi-ws281x/rpi-ws281x-python)', which is among the libraries installed via the `pip install -r requirements.txt` command. LED configuration is changed from the _Advanced Settings_ page.

The `Count` value must be set to the Number of LED pixels connected. LEDs will not operate is this value is 0. The following items may also be configured:

* `Panel Rows`: Number of rows in a multiline LED display panel. `Count` must be evenly divisible by this value.
* `Panel Rotation`: Rotates panel images in 90° increments
* `Panel Row Ordering`: Enables column inversion for even-numbered rows
* `GPIO Number`: GPIO number which is connected to the pixels; this not the hardware pin index (default 10 uses SPI '/dev/spidev0.0')
* `Frequency (Hz)`: LED signal frequency in hertz (usually 800000)
* `DMA`: DMA channel to use for generating signal (default 10)
* `Inverted Control Signal`: Inverts the control signal for use with NPN transistor level shift
* `Channel`: Set to '1' for GPIOs 13, 19, 41, 45 or 53
* `Strip Type`: Signal color ordering (default is 'GRB')
* `Serial Controller Port`: Port identifier for an externally-connected [LED Controller](#led-controller)
* `Serial Controller BAUD` : BAUD rate of communication to external controller

Running LEDs from certain GPIOs (such as GPIO 18) requires the server to be run as root. If the error message `Can't open /dev/mem: Permission denied` or `mmap() failed` appears on startup, you must connect LEDs to a different GPIO or run the server with `sudo`. If using a "rotorhazard.service" file to [start the server on boot](#start-on-boot), it may be run as root by leaving out the "User=pi" line.

See also the [WS2812b LED Support](Hardware%20Setup.md#ws2812b-led-support) section in [doc/Hardware Setup.md](Hardware%20Setup.md).

#### LED Panel Support

Additional LED effects for a two-dimensional LED display (panel) are available by installing image manipulation libraries.
```
sudo apt-get install libjpeg-dev
pip install pillow
sudo apt-get install libopenjp2-7-dev
```

- `Panel Rows` **must be set** for multiline displays. 
- If your multiline panel image requires rotation, use `Panel Rotation`. 
- If alternating lines appear jumbled, try changing the `Panel Row Ordering`.

#### Raspberry Pi 5

When the hardware is a Raspberry Pi 5, the '[rpi5-ws2812](https://github.com/niklasr22/rpi5-ws2812)' library is used (because the '[rpi-ws281x](https://github.com/jgarff/rpi_ws281x)' library does not support the Pi 5). This library should cover most use cases, but the following LED configuration parameters are not supported (and will be ignored):
- GPIO Pin (only GPIO10 supported)
- Strip Type (only GRB supported)
- Frequency
- DMA
- Inverted Control Signal
- Channel

If the LED count is more than 50, the SPI buffer size should be increased by adding " spidev.bufsiz=65536" to the first line of '/boot/firmware/cmdline.txt' file on the Pi. The following command will add the text and display the contents of the file:
```commandline
if [ -f "/boot/firmware/cmdline.txt" ] && ! grep -qF 'spidev.bufsiz' /boot/firmware/cmdline.txt; then echo && sudo sh -c 'sed -i "1 s/$/ spidev.bufsiz=65536/" /boot/firmware/cmdline.txt'; fi && cat /boot/firmware/cmdline.txt && echo
```

#### LED Controller

An alternative to the above methods is to use an LED Controller module, which may be connected to a USB port on any computer that is running the RotorHazard Server. See the [LED Controller repository](https://github.com/RotorHazard/LEDCtrlr) for details on how to wire and program an Arduino board as an LED controller.

### Java Support
Java enables the calculating of IMD scores, which is helpful for selecting frequency sets with less interference between VTXs. To determine if Java is installed, run the following command:
```
java -version
```
If the response is "command not found" then Java needs to be installed.

For the Raspberry Pi 3 or newer, use the following command:
```
sudo apt install default-jdk-headless
```

For the Raspberry Pi Zero (or an older-model Pi), use this command:
```
sudo apt install openjdk-8-jdk-headless
```

----------------------------------------------------------------------------

## Updating an Existing Installation

Before updating, any currently-running RotorHazard server should be stopped. If installed as a service, it may be stopped with a command like:
```
sudo systemctl stop rotorhazard
```

The minimum version of Python supported is 3.10. If the installed version is older, it should be upgraded before upgrading RotorHazard. You can check the current version on the command line using `python --version`. This wiki article covers a method to [install a newer version of Python](https://github.com/RotorHazard/RotorHazard/wiki/Installing-Newer-Versions-of-Python-on-the-Raspberry-Pi).

To update to the [latest stable release](https://github.com/RotorHazard/RotorHazard/releases/latest), enter the following commands:

```bash
cd ~
wget https://rotorhazard.com/update.sh
sh update.sh
```

To upgrade to another version, add the desired version code after `update.sh` - for example:
```bash
sh update.sh v4.3.0-beta.1
```

Note:
* The updates for the RotorHazard server Python dependencies may take a few minutes
* Error messages about "pip's dependency resolver ... Flask-SQLAlchemy not installed" may be safely ignored
* The previous "RotorHazard" directory will be archived as: "old/RotorHazard_YYYYMMDD_HHMMSS" (with the current date/time)

----------------------------------------------------------------------------

## Other Operating Systems

The RotorHazard server may be run on any computer with an operating system that supports Python. In these alternate configurations, one or more hardware nodes may be connected via USB -- see [doc/USB Nodes.md](USB%20Nodes.md) for more information. The server may also be run using simulated (mock) nodes. (See also the [doc/Windows Run Script.md](Windows%20Run%20Script.md) documentation.)

**To install the RotorHazard server on these systems:**

1. If the computer does not already have Python installed, download and install Python from https://www.python.org/downloads . The minimum version of Python needed for RotorHazard is 3.10. To check if Python is installed and the version, open up a command prompt and enter ```python --version```

2. From the RotorHazard [Releases page on github](https://github.com/RotorHazard/RotorHazard/releases), download the "Source code (zip)" file.

3. Unzip the downloaded file into a directory (aka folder) on the computer.

4. Open up a command prompt and navigate to the topmost RotorHazard directory.

5. Create a Python virtual environment ('venv') by entering: ```python -m venv --system-site-packages .venv```

6. Activate the Python virtual environment ('venv'):

  * On a Windows system the command to use will likely be: ```.venv\Scripts\activate.bat```

  * On a Linux system the command to use will likely be: ```source .venv/bin/activate```

7. Using the same command prompt, navigate to the ```src/server``` directory in the RotorHazard files (using the 'cd' command).

8. Install the RotorHazard server dependencies using the 'reqsNonPi.txt' file, using one of the commands below. (Note that this command may require administrator access to the computer, and the command may take a few minutes to finish).

  * On a Windows system the command to use will likely be:<br/>```python -m pip install -r reqsNonPi.txt```<br>

Note: If the above command fails with a message like "error: Microsoft Visual C++ 14.0 is required", the "Desktop development with C++" Tools may be downloaded (from [here](https://aka.ms/vs/17/release/vs_BuildTools.exe)) and installed to satisfy the requirement.<br>

  * On a Linux system the command to use will likely be:<br/>```pip install -r reqsNonPi.txt```

**To run the RotorHazard server on these systems:**

1. Open up a command prompt and navigate to the topmost RotorHazard directory.

2. Activate the Python virtual environment ('venv')
  * On a Windows system the command to use will likely be: ```.venv\Scripts\activate.bat```

  * On a Linux system the command to use will likely be: ```source .venv/bin/activate```

3. Using the same command prompt, navigate to the ```src/server``` directory.

4. Enter: ```python server.py```

5. If the server starts up properly, you should see various log messages, including one like this:
    ```
    Running http server at port 5000
    ```

1. The server may be stopped by hitting Ctrl-C

If hardware nodes are connected via USB, they will need to be configured in the _Serial Ports_ section on the _Advanced Settings_ page in the _Hardware_ panel (see [doc/USB Nodes.md](USB%20Nodes.md) for details).

If no hardware nodes are configured, the server will operate using simulated (mock) nodes. In this mode the web-GUI interface may be explored and tested.

To view the web-GUI interface, open up a web browser and enter into the address bar: ```localhost:5000``` (If the HTTP_PORT value in the configuration has been changed then use that value instead of 5000). If the server is running then the RotorHazard main page should appear. Note that pages reserved for the race director (Admin/Settings) are password protected with the username and password specified in the configuration.

**To update an existing installation:**

1. From the RotorHazard [Releases page on github](https://github.com/RotorHazard/RotorHazard/releases), download the "Source code (zip)" file.

2. Unzip the downloaded file into the RotorHazard directory (aka folder) on the computer, overwriting the existing version.

3. Using the command prompt, navigate to the topmost RotorHazard directory.

4. Activate the Python virtual environment ('venv'):

  * On a Windows system the command to use will likely be: ```.venv\Scripts\activate.bat```

  * On a Linux system the command to use will likely be: ```source .venv/bin/activate```

5. Using the command prompt, navigate to the ```src/server``` directory.

6. Enter the update command:

  * On a Windows system the command to use will likely be:<br/>```python -m pip install --upgrade --no-cache-dir -r reqsNonPi.txt```

  * On a Linux system the command to use will likely be:<br/>```pip install --upgrade --no-cache-dir -r reqsNonPi.txt```
<br>

----------------------------------------------------------------------------

## Viewing Database Files

A "snapshot" copy of the database file used by the RotorHazard server may be downloaded using the `Backup Database` button in the 'Data Management' section on the 'Format' page in the RotorHazard web GUI. A tool like [DB Browser for SQLite](https://sqlitebrowser.org) may be used to view the raw data in the file.

A database file may be loaded into the RotorHazard server via the "--viewdb" command-line argument:
```
python server.py --viewdb dbFileName.db [pagename] [browsercmd]
```
The current server database is backed up and the specified one is loaded. If a 'pagename' value (i.e., "results") is given then a web browser is launched showing the RotorHazard web GUI at the specified page. If a 'browsercmd' value is given then that command is used to launch the web browser (for instance, a value of "C:\Program Files\Mozilla Firefox\firefox.exe" could be specified to launch the Firefox browser on a PC where is it installed but is not the default browser).

The "--launchb" command-line argument can be specified to launch a web browser after the server starts up:
```
python server.py --launchb [pagename] [browsercmd]
```

----------------------------------------------------------------------------

## RotorHazard Portable

A "portable" version of the RotorHazard server, which can be useful for viewing database files on a Windows PC, may be found [here](http://www.rotorhazard.com/portable). To use it, download the "rhPortable...zip" file, unpack it into a local directory, and then drag-and-drop a database file onto the 'runRotorHazard' batch file. This will launch a local copy of the RotorHazard server, load the database file, and launch a web browser for viewing the GUI. Sample RotorHazard database files may be found [here](http://www.rotorhazard.com/dbsamples). The server can be terminated by entering Ctrl-C on its console window.

(The "rhPortable...zip" file includes the needed Python support. The the 'runRotorHazardFF' batch file will attempt to launch the Firefox browser.)

----------------------------------------------------------------------------

## Logging

The RotorHazard server generates "log" messages containing information about its operations. You may change log settings from the _Advanced Settings_ page.

The following log levels may be specified:  DEBUG, INFO, WARNING, WARN, ERROR, FATAL, CRITICAL, NONE

If the `Logfile Level` value is not NONE then the server will generate log files in the `[rh-data]/logs` directory. A new log file is created each time the server starts, with each file having a unique name based on the current date and time (i.e., "rh_20200621_181239.log"). Setting `Logfile Level` to DEBUG will result in more detailed log messages being stored in the log file, which can be useful when debugging problems.

The `Logfile Retention` value is the number of log files to keep; the rest will be deleted (oldest first).

The `Console Stream` value may be "stdout" or "stderr".

If the `System Log Level` value is not NONE then the server will send log messages to the logging utility built into the host operating system.

The current Server Log may be displayed via the "View Server Log" item in the drop-down menu. The displayed log is "live" in that it will update as new messages are generated. The log can be displayed in a separate window by clicking on the "View Server Log" menu item with the right-mouse button and selecting the "Open Link in New Window" (or similar) option.

Clicking on the "Select Text" button will select all the displayed log text, which may then be copied and pasted. Clicking on the "Download Logs" button will create and download a '.zip' archive file containing all available log files and the current configuration and database files. The '.zip' archive file can also be generated by running the server with the following command:  `python server.py --ziplogs`

**When reporting issues, using the "Download Logs" button and including the generated '.zip' file is highly recommended.**

When troubleshooting, another place to check for error messages is the system log file, which may be viewed with a command like: `journalctl -n 1000`

<br/>

-----------------------------

See Also:<br/>
[doc/Hardware Setup.md](Hardware%20Setup.md)<br/>
[doc/USB Nodes.md](USB%20Nodes.md)<br/>
[doc/User Guide.md](User%20Guide.md)<br/>
[Build Resources (PCB, etc) &#10132;&#xFE0E;](https://github.com/RotorHazard/RotorHazard/tree/main/resources/README.md)

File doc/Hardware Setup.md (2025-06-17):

# Hardware Setup Instructions

See the [RotorHazard Build Resources &#10132;&#xFE0E;](https://github.com/RotorHazard/RotorHazard/tree/main/resources/README.md) page for information on race-timer circuit boards and 3D-printable cases.

For general information on the Arduino-nodes version of the timer, see '[doc/Timer Build with Arduinos.md](Timer%20Build%20with%20Arduinos.md)'

### RX5808 Video Receivers
RotorHazard requires RX5808 modules to have SPI communication enabled in order to change channels. Some receivers arrive without this set up. If SPI is not enabled, the receivers will not listen or change channels correctly. If this happens, modify the RX5808 receivers to enable SPI support as follows:

> [!IMPORTANT]
> 
> If RotorHazard is receiving video signal input but does not appear to be responding correctly when transmitters are powered on, do this modification. 

> [!TIP]
> 
> It is safe—and generally necessary—to first install the module before knowing if this modification is needed.  

Remove the shield from the RX5808, the shield is normally held on by a few spots of solder around the edges. Use some solder wick to remove the solder and free the shield from the receiver. Be careful not to damage any ground pads on the receiver. There are usually small holes around the edge you can use to help push off the shield.

Remove the following resistor:

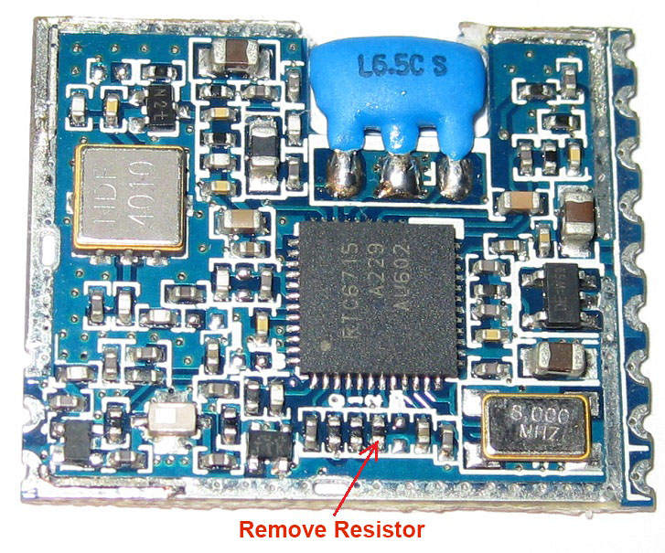
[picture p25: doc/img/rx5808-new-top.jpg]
RX5808 spi mod


The shield should be soldered back in place after removing the resistor.

### Add a Directional RF Shield
A directional RF shield significantly improves the system's ability to reject false passes. See [RF shielding](Shielding%20and%20Course%20Position.md)

### Real Time Clock
See '[doc/Real Time Clock.md](Real%20Time%20Clock.md)' for more information on installing a real-time clock module to improve how the system maintains its date and time.

### WS2812b LED Support

For the [S32_BPill board](../resources/S32_BPill_PCB/README.md) connect to J6 "Pi_LED" (near the middle of the board); pin 1 is ground, pin 2 is signal.

For the [6 Node STM32](../resources/6_Node_BPill_PCB/README.md) board use the 'LEDS' connector.

For the [RotorHazard PCB 1.2 board](../resources/PCB/README.md) use the LED OUT connector (beware of overloading the 5V power supply).

See [WS2812b LED Support](Software%20Setup.md#ws2812b-led-support) under [doc/Software Setup.md](Software%20Setup.md).

For direct wiring to the Pi: The pins in the green box is what were already used by the timer. The pins in the red box is where you connect the signal and ground from the ws2812b LEDs.  The LEDs will require a separate power source.

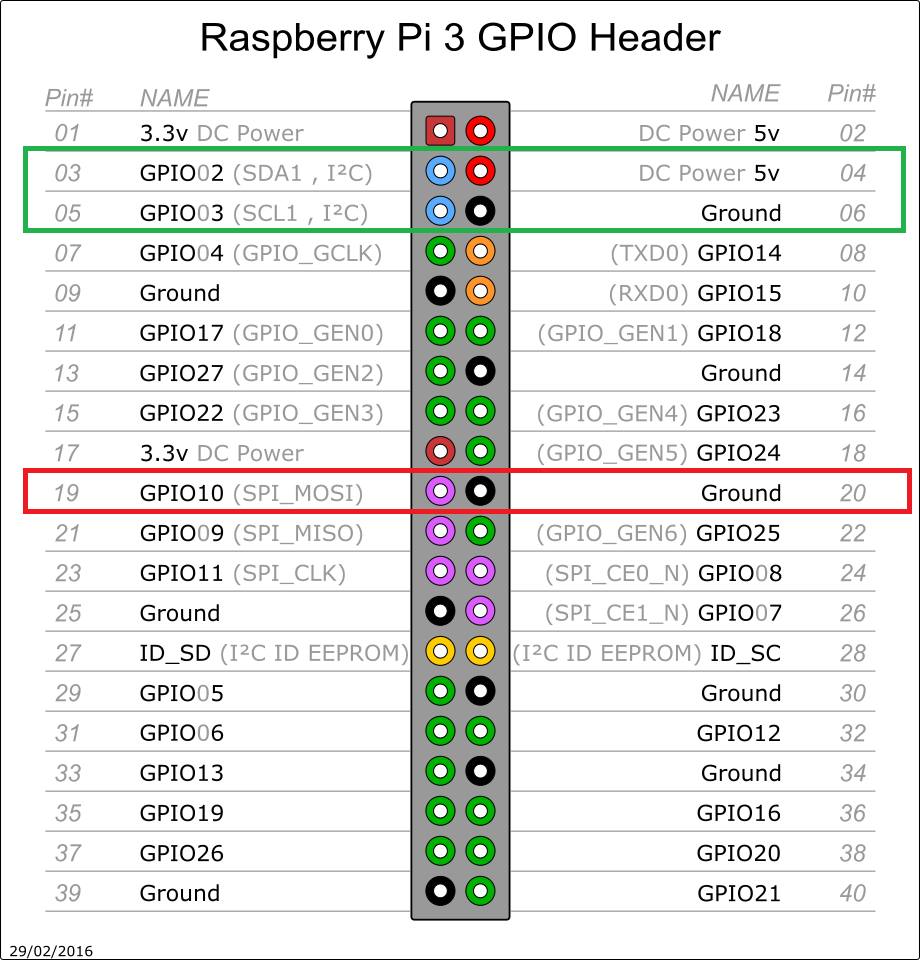
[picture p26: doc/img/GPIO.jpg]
led wiring


### Additional Sensors
Sensors (such as BME280 and INA219) may be attached to the I2C bus and power pins. See the '..._sensor.py' files in the "src/interface" directory for implementation examples. Sensors need to be added to the server configuration on the _Settings_ page in the _Environment Sensors_ panel. Type the sensor's address into the `Address` input and complete the entry (click outside or use the tab key to defocus). A new `Sensor` section will be added. Add multiple items if desired, or clear the `Address` to remove. You can similarly add and remove key/value pairs to configure individual sensor types. All sensors support the `name` key, but individual sensors may use other keys. For example, a battery sensor may have a `max_current` configuration key.

### Multiple Timers
Multiple RotorHazard timers may be connected together (i.e., for split timing and mirroring) -- see [doc/Cluster.md](Cluster.md).

-----------------------------

See Also:<br/>
[doc/USB Nodes.md](USB%20Nodes.md)<br/>
[doc/Software Setup.md](Software%20Setup.md)<br/>
[doc/User Guide.md](User%20Guide.md)<br/>
[Build Resources (PCB, etc) &#10132;&#xFE0E;](https://github.com/RotorHazard/RotorHazard/tree/main/resources/README.md)

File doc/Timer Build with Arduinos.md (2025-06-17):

# Timer Build with Arduinos

## Parts List

### Receiver Node(s) (this list makes one node, build up to eight)
* 1 x [Arduino Nano](https://www.ebay.com/sch/i.html?_nkw=Arduino+Nano+V3.0+16M+5V+ATmega328P)
* 1 x [RX5808 module](https://www.banggood.com/search/rx5808-module.html) with SPI mod (see below)
* 3 x 1k ohm resistor
* 1 x 100k ohm resistor
* 26 AWG and 30 AWG silicone wire

### System Components
* 1 x Raspberry Pi3 (Pi2 users have reported issues with multiple nodes connected)
* 8 GB (minimum) Micro SD Card
* 26 AWG and 30 AWG silicone wire (for wiring to each receiver node)
* 3D printed case for housing the electronics
* 5V power supply, 3 amp minimum (or 12V power supply if onboard regulators are used)

### Additional Components
* [RF shielding](Shielding%20and%20Course%20Position.md)

### Optional Components
* Ethernet cable, 50ft plus
* Outdoor power cable, 50ft plus
* Network router
* Laptop/tablet
* ws2812b LEDs

## Hardware Setup

### RX5808 Video Receivers
RX5808 modules may need a small hardware modification in order to change channels. See [General Hardware Setup](Hardware%20Setup.md#rx5808-video-receivers) for more information.

### Receiver Nodes
Complete wiring connections between each Arduino and RX5808.
receiver node wiring

Note: A simple receiver node may also be constructed and attached via USB -- see [doc/USB Nodes.md](USB%20Nodes.md).

### System Assembly
Complete wiring connections between each Arduino and the Raspberry Pi.

Note: be sure all Receiver Nodes and the Raspberry Pi are tied to a common ground; if not, the i2c messages can be corrupted.
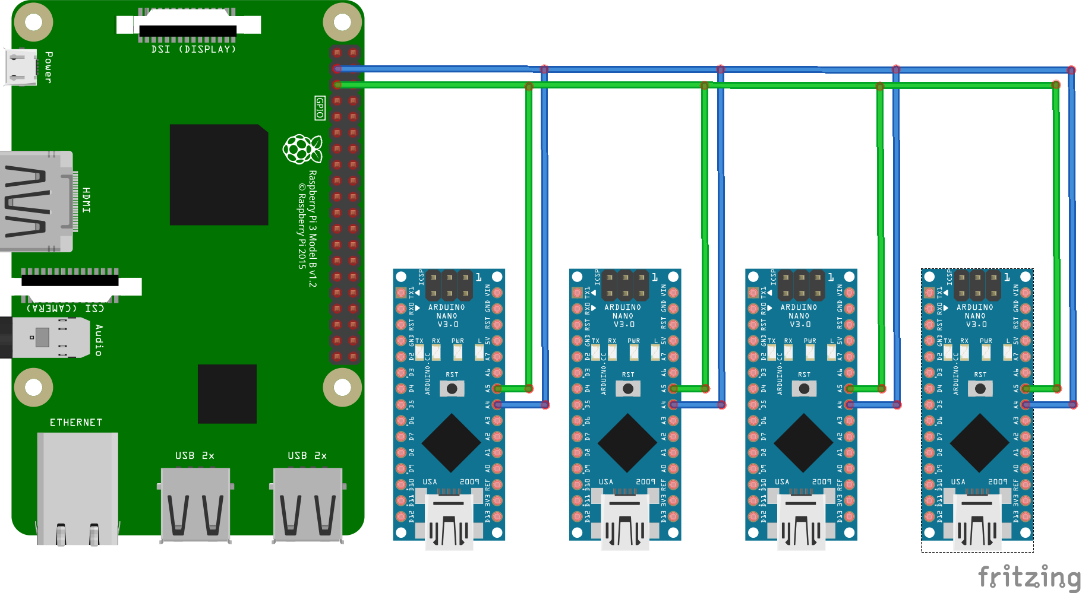
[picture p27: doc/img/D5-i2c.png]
system wiring


-----------------------------

See Also:<br/>
[doc/Hardware Setup.md](Hardware%20Setup.md)<br/>
[doc/USB Nodes.md](USB%20Nodes.md)<br/>
[doc/Software Setup.md](Software%20Setup.md)<br/>
[doc/User Guide.md](User%20Guide.md)<br/>
[Build Resources (PCB, etc) &#10132;&#xFE0E;](https://github.com/RotorHazard/RotorHazard/tree/main/resources)

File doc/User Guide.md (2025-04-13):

# RotorHazard Race Timer User Guide

- [Initial Setup](#initial-setup)
    - [Hardware and Software Setup](#hardware-and-software-setup)
    - [Connect to the Server](#connect-to-the-server)
- [Pages](#pages)
    - [Home](#home)
    - [Event](#event)
    - [Results](#results)
    - [Current](#current)
    - [Format](#format)
    - [Settings](#settings)
    - [Run](#run)
    - [Marshal](#marshal)

## Initial Setup

### Hardware and Software Setup
Follow the instructions here if not done already:<br>
[Hardware Setup](Hardware%20Setup.md)<br>
[Software Setup](Software%20Setup.md)<br>
[RF shielding](Shielding%20and%20Course%20Position.md)

### Connect to the Server
A computer, phone or tablet may be used to interact with the race timer by launching a web browser and entering the IP address of the Raspberry Pi. The Raspberry Pi may be connected using an ethernet cable, or to an available WiFi network. If the IP address of the Pi is not known, it may be viewed using the terminal command "ifconfig", and it can configured to a static value on the Pi desktop via the "Network Preferences." If the Pi is connected to a WiFi network, its IP address may be found in the 'Clients' list on the admin page for the network's router.

In the web browser, type in the IP address of for the race timer and the port value you set in the config file. (You may leave off the :port if set to 80 or [port forwarding from 80](Software%20Setup.md#enable-port-forwarding) is enabled.)

```
XXX.XXX.XXX.XXX:5000
```

Once the page is successfully displayed, it may be bookmarked in the browser. Pages reserved for the race director ("Admin / Settings") are password protected with the username and password specified in the config file.

## Pages

### Home

This page displays the event name and description, along with a set of buttons to various other pages.

### Event

This public page displays the current class setup (if applicable), and a summary of pilots and their heats with channel assignment.

### Results

This public page will display results and calculated statistics of all previously saved races, organized into collapsible panels. Aggregate results are displayed for each heat with multiple rounds, each class, and the entire event.

### Current

This page displays information about the currently running race, including real-time race time, pilot lap times and leaderboard. It automatially updates with the event, and is suitable for projecting to a prominently displayed screen.

In the Audio Control section, the user can select whether any one pilot, all pilots, or no pilots will have laps announced. In this way, a pilot might elect to hear only their own laps announced. A user can also adjust the voice, volume, rate, and pitch of these announcements.

### Format

This page is for adjusting event-specific parameters.

#### Event
Event information is displayed to users, such as on the home page when users first connect to the system or at the top of the Results page.

_Consecutive Laps Base_ sets the number of laps which RotorHazard calculates for its Consecutive Laps race formats and results.

_Minimum Lap Time_ and _Minimum Lap Behavior_ change how RotorHazard highlights or discards short passes. _Minimum Lap Time_ changes the threshold under which will activate the _Minimum Lap Behavior_. Use the "discard" behavior with caution, as this will eliminate data that may have been valid.

#### Pilots
Add an entry for each pilot that will race. The system will announce pilots based on their callsign. A phonetic spelling for a callsign may be used to influence the voice callouts; it is not required.

_Pilot Sort_ affects how pilot selectors in the RotorHazard interface will be sorted. Reloading the page may be necessary to see the effects.

_Color Mode_ affects how RotorHazard assigns colors to pilots in each race.
- "Seat": assigns a color based on which seat a pilot is slotted into for the race
- "Pilot": assigns a color based on the color value chosen in the pilot list
- "Frequency": assigns a color based on the frequency selected for the seat, per the color standard established by Betaflight

#### Classes and Heats
Classes are groups of heats and races that share common characteristics. Each class will have its own results and ranking calculated separately from others. Classes are not required for events but are generally recommended. Class results can be useful for seeding multiple events phases, such as qualifying into finals. Create a class (if desired) and add heats to it.

Classes may be given a name and description in addition to other properties:
- _Race Format_: if selected, this race format is force-applied to all races in the class
- _Ranking_: method by which this class is ranked. May be extended by plugins
- _Rounds_: number of rounds after which RotorHazard considers the heat to be done; leave at 0 to continue running this class until another is manually chosen
- _Advance Heat_: determines whether RotorHazard will automatically move to the next heat when a race in this class concludes

Heats are groups of pilots racing together simultaneously. Heats contain slots where you assign pilots who will race. Optional heat names can be added if desired. The number of slots available is determined by the hardware configuration of the timer. Each slot has a mode and assignment criteria. Heat slots may be set to *None* to prevent a pilot from being assigned.
- "Pilot": directly assigns a pilot to this race slot
- "Heat": Use the results of another heat when seeding this heat. When selected, choose the heat to seed from and the ranking position that will be used
- "Class": Use the results of a class when seeding this heat. When selected, choose the class to seed from and the ranking position that will be used

If "Auto Frequency" is on, slots are not assigned to seats (and frequencies) until a heat is seeded. This is strongly recommended if the "Heat" or "Class" methods are used.

If any of the slots uses either "Heat" or "Class" method, or if "Auto Frequency" is on, dynamic seeding becomes active for the heat.

A dynamically seeded heat can be in the "Plan" or "Seeded" state. A newly created heat is in the Plan state, and a race cannot be run until the heat is seeded. You may seed a heat using the "Seed Now" button, which will pull the current results from any selected heats and classes to create pilot assignments. If "Auto Frequency" is on, slots (and frequencies) are also assigned during this step. Plan heats are seeded when selected on the [Run](#run) page. If you confirm the assignments shown, the heat becomes seeded. Seeded heats that have not yet been used to run a race can be switched back to the "Plan" state using the "Revert to Plan" button. Note that seeding is not deterministic; reseeding may not produce the same results.

As you run races, classes and heats will become locked and cannot be modified. This protects saved race data from becoming invalid. You may unlock heats and classes to modify their data. If you do, you are rewriting race history for those heats and classes as if they were set up from the beginning. _If you wish to make a change to a heat going forward only and without affecting race history, duplicate the heat to create a new one._ Clearing races from the event will unlock all heats and classes.

#### Generators

Generators create classes and heats. Several generators are built into RotorHazard by default, and additional generators may be available if added by plugin.

_Generator_ selects which method to use.
_Input_ chooses which class will be used to seed the generated heats. Choose "-All Pilots-" to use every currently loaded pilot with no regard for ranking.
_Output_ selects where to place the generated results. Choose "-New Class-" to have RotorHazard create a class where the results will be placed.

If a generator has additional parameters, they will appear when the "Generate Heats" button is pressed.

- _Balanced Random Fill_: Fills heats randomly from the input pool, keeping the number of pilots in each heat as consistent as possible.
    - _Maximum pilots per heat_: Limits the total number of pilots that are drawn from the input pool for each heat; if _Auto_, will use the current number of seats which are not disabled
    - _Maximum pilots in class_: Limits the total number of pilots that are drawn from the input pool for the class, if an input class is selected
    - _Seed from rank_: Skips pilots before seeding; useful for "next 16"-type brackets
    - _Heat title suffix_: Modifies the name of generated heats
- _Ladder_: Generates ladder (sometimes called "letter") heats
    - _Advances per heat_: Number of pilots which will advance (or "bump") up to the next higher ladder heat (0 is acceptable)
    - _Seeded slots per heat_: Number of pilots which are seeded into each ladder heat from the input pool
    - _Pilots in class_: Limits the total number of pilots that are drawn from the input pool for the class, if an input class is selected
    - _Seed from rank_: Skips pilots before seeding; useful for "next 16"-type brackets
    - _Heat title suffix_: Modifies the name of generated heats
- _Ranked Fill_:
    - _Maximum pilots per heat_: Limits the total number of pilots that are drawn from the input pool for each heat; if _Auto_, will use the current number of seats which are not disabled
    - _Maximum pilots in class_: Limits the total number of pilots that are drawn from the input pool for the class, if an input class is selected
    - _Seed from rank_: Skips pilots before seeding; useful for "next 16"-type brackets
    - _Heat title suffix_: Modifies the name of generated heats
- _Regulation bracket, double elimination_:
    - _Spec_: Regulation to follow for generating brackets
    - _Seed from rank_: Skips pilots before seeding; useful for "next 16"-type brackets
- _Regulation bracket, single elimination_:
    - _Spec_: Regulation to follow for generating brackets
    - _Seed from rank_: Skips pilots before seeding; useful for "next 16"-type brackets

#### Race Formats
Race formats define how an individual race is conducted. Choose a format to adjust.

The "+" button will duplicate the current race format, and the "x" button will remove the current race format. (Once a race format is removed it cannot be recovered, but default formats may be restored from the Data Management panel.)

The race clock can count up or down as selected by _Race Clock Mode_. Use "No Time Limit" for a "First to X laps" style with a timer that counts upward from zero. Use "Fixed Time" for a timer which counts down to zero after the race starts. _Timer Duration_ is used in "Fixed Time" mode to determine race length.

During a "Fixed Time" race, _Grace Period_ is the amount of time after the race clock expires before the timer is automatically stopped. Set _Grace Period_ to "0" to stop a race immediately when time expires. If _Grace Period_ is set to "-1", the clock continues indefinitely and must be stopped manually.

Each race begins with a staging sequence. Adjust the _Prestage Tones_ value to control the length of the *prestage* phase, during which one tone will sound each second. Next is the *staging* phase, which can be a fixed or random duration. _Minimum Staging Time_ sets a fixed minimum duration for the *staging* phase. If _Random Staging Time_ is greater than zero, the timer will additionally delay randomly between zero and this value. Setting _Random Staging Time_ above zero also hides the staging clock, which will show "Ready" instead of a countdown. Choose whether tones are heard during the *staging* phase with _Staging Tones_.

##### Examples:
* A fixed "3, 2, 1, Go" countdown start:
    * _Prestage Tones_: 3
    * _Staging Tones_: (any)
    * _Minimum Staging Time_: 1.0
    * _Random Staging Time_: 0.0
* 1 prestage tone followed by a start tone within 1–5 seconds:
    * _Prestage Tones_: 1
    * _Staging Tones_: None
    * _Minimum Staging Time_: 1.0
    * _Random Staging Time_: 5.0
* 5 prestage tones followed by a random delay between 0.2 and 3.0 seconds:
    * _Prestage Tones_: 5
    * _Staging Tones_: None
    * _Minimum Staging Time_: 0.2
    * _Random Staging Time_: 2.8
* A variable number of tones between 2 and 5, then start:
    * _Prestage Tones_: 2
    * _Staging Tones_: Each Second
    * _Minimum Staging Time_: 0.2
    * _Random Staging Time_: 3.7

_A small amount of time is needed to ensure the timer has synchronized with all hardware, so there is always a short period to start a race even with all staging times set to zero._

When a pilot crosses for the first time in a race, _First Crossing_ affects how result displays and race outcomes are processed. "Hole Shot" records the race time of each pilot's first crossing as beginning their first lap. "First Lap" records the race time of each pilot's first crossing as ending their first lap. "Staggered Start" begins each pilot's own race clock their first crossing, disregarding the global race clock. "Staggered Start" is typically combined with the "No Time Limit" _Race Clock Mode_.

_Win Condition_ determines how the timer calls out the winner of the race, the information presented in the OSD and streaming display, and sort method for leaderboards. Leaderboard sorting affects the results page and heat generator.
* __Most Laps in Fastest Time__: Pilots are judged by the number of laps completed and how long it took to complete them. If there is a tie for the number of laps completed, the pilot who completed those laps in a shorter amount of time will be ranked higher.
* __Most Laps Only__: Scored only by the completed lap count. Pilots with the same lap count are tied. Use with "Fixed Time" mode for a race style before timing was reliable, or with "No Time Limit" mode to judge the greatest distance instead of shortest time.
* __Most Laps Only with Overtime__: Similar to _Most Laps in Fastest Time_, but with a "sudden death" component. When the timer expires (or the race is stopped early), if a pilot has more laps than all the others then that pilot is the winner. If there is a tie for lap count when the timer expires, the first of the tied pilots across the line is the winner.
* __First to X Laps__: The race continues until one pilot reaches the desired lap count. In this mode, the _Number of Laps to Win_ parameter is used. Typically used with the _No Time Limit_ race mode.
* __Fastest Lap__: Ignores the race progress and considers only each pilot's single fastest lap.
* __Fastest 3 Consecutive Laps__: Considers all laps a pilot has completed and uses the three consecutive laps with the fastest combined time.
* __None__: Does not declare a winner under any circumstance. Heats generated from a class with this condition will be assigned randomly.

__Team/Co-op Racing Mode__ provides access to racing modes in which pilots may compete together in groups. 

__Team Racing__ allows groups of pilots to complete as teams. The team for each pilot may be set in the 'Pilots' section. Win conditions in team racing mode differ somewhat:
* __Most Laps in Fastest Time__: Teams are judged on combined lap count of all members and how long it took to complete those laps.
* __Most Laps Only__: Teams are judged on total combined lap count of all members.
* __Most Laps Only with Overtime__: Teams are judged on total combined lap count of all members. If tied when time expires, the first team (of those tied) to add a lap becomes the winner.
* __First to X Laps__: The first team to complete the desired combined lap count is the winner.
* __Fastest Lap__: After all team members have contributed one lap, teams are judged by the average of pilots' fastest lap time.
* __Fastest 3 Consecutive Laps__: After all team members have contributed 3 laps, teams are judged by the average of pilots' fastest "three consecutive laps" time.

With _Fastest Lap_ and _Fastest 3 Consecutive Laps_, teams with differing numbers of pilots can compete together fairly.

__Co-op Racing__ allows all pilots in a race to work as a cooperative group to improve their combined performance. Pilots of varying abilities can race together, with everyone contributing and working on improving their skills. There are two versions of co-op racing, described below. In both versions, all pilots in the current heat race together as a group. In the first race, a benchmark performance is set, and in each race after that the group attempts to improve and achieve a new best performance. 

* _Co-op Fastest Time to X Laps_: The group attempts to complete the given number of laps (X) in the fastest time. When this racing format is enabled (on the 'Run' page), the current "Co-op Best Time" value will be shown in the "Race Management" section, and the value may be altered or cleared there.  

* _Co-op Most Laps in X:XX_: The group attempts to complete the most number of laps in the given race time (X:XX). When this racing format is enabled (on the 'Run' page), the current "Co-op Best # of Laps" value will be shown in the "Race Management" section, and the value may be altered or cleared there.

The "%COOP_RACE_INFO%" and "%COOP_RACE_LAP_TOTALS%" variables can be used in callouts with co-op races, see the [Event Actions](#event-actions) section for descriptions. 

#### Data Management

_Stored Data_ can be used to backup the current database (save to a file on the pi and prompt to download it) or restore events from stored data files

_Reset_ may clear races, classes, heats, pilots, and race formats

_Import_ uses plugins to extract data from files and fill event values

_Export_ uses plugins to extract event values and save to files

### Settings

This page allows changing the timer's optional settings and event setup.

#### Frequency Setup
Choose a preset or manually select frequencies for each node. Arbitrary frequency selection is possible, as is disabling a node. The IMD score for currently selected frequencies is calculated and displayed at the bottom of the panel.

Profiles contain frequencies and node tuning values. Changing this list immediately activates the selected profile, and changing current frequencies and node tuning immediately saves to the profile.

#### Sensor Tuning
See [doc/Tuning Parameters.md](Tuning%20Parameters.md) for a detailed description and tuning guide.

#### Audio Control
All audio controls are local to the browser and device where you set them, including the list of available languages, volumes, and which announcements or indicators are in use.

Voice select chooses the text-to-speech engine. Available selections are provided by the web browser and operating system.

Announcements allow the user to choose to hear each pilot's callsign, lap number, and/or lap time as they cross. The "Race Clock" announcement will periodically call out how much time has elapsed or is remaining, depending on the timer mode in the race format. "Team/Co-op Lap Total" applies when "Team Racing Mode" or "Co-op Racing Mode" is enabled, and configures whether or not the lap total for the pilot group is announced on each lap. The "On Team/Co-op Races (short call)" option will result in a short version of the callout (simply "Lap X").

Voice volume, rate, and pitch control all text-to-speech announcements. "Tone Volume" controls race start and end signals.

Indicator beeps are very short tones that give feedback on how the timer is working, and are most useful when trying to tune it. Each node is identified with a unique audio pitch. "Crossing Entered" will beep once when a pass begins, and "Crossing Exited" will beep twice rapidly when a pass is completed. "Manual Lap Button" will beep once if the "Manual" button is used to force a simulated pass.

If you select "Use MP3 Tones instead of synthetic tones" then the '.mp3' files at "src/server/static/audio" will be used to play the tones. (This is necessary on some web browsers and operating systems.)

#### Event Actions
Extend and personalize your timer's behavior by attaching *Effects* to *Events*. The timer generates an *Event* on race start, lap recorded, pilot done, etc. *Effects* are behaviors that can be triggered. Each effect may have parameters which can be configured.

For example, you might add the "Speak" effect to the "Pilot Done" event in order to call out when each pilot has completed their own laps.

* _Speak_ produces an audible voice callout
* _Message_ creates a standard text notification
* _Alert_ creates a priority (pop-up) alert message

The variables listed below may be used for the  effects.

| Variable | Description |
|---|---|
| %PILOT% | Pilot callsign |
| %HEAT% | Current heat name or ID value |
| %ROUND% | Current round number |
| %ROUND_CALL% | Current round number (with prompt) |
| %RACE_FORMAT% | Current race format |
| %LAP_COUNT% | Current lap number |
| %LAST_LAP% | Last lap time for pilot |
| %AVERAGE_LAP% | Average lap time for pilot |
| %FASTEST_LAP% | Fastest lap time |
| %TIME_BEHIND_CALL% | Amount of time behind race leader (with prompt) |
| %TIME_BEHIND_FINPOS_CALL% | Pilot NAME finished at position X, MM:SS.SSS behind |
| %TIME_BEHIND_FINPLACE_CALL% | Pilot NAME finished in X place, MM:SS.SSS behind |
| %FASTEST_SPEED% | Fastest speed for pilot |
| %CONSECUTIVE% | Fastest consecutive laps for pilot |
| %TOTAL_TIME% | Total time since start of race for pilot |
| %TOTAL_TIME_LAPS% | Total time since start of first lap for pilot |
| %POSITION% | Race position for pilot |
| %POSITION_CALL% | Race position for pilot (with prompt) |
| %POSITION_PLACE% | Race position (first, second, etc) for pilot |
| %POSITION_PLACE_CALL% | Race position (first, second, etc) for pilot (with prompt) |
| %FASTEST_RACE_LAP% | Pilot/time for fastest lap in race |
| %FASTEST_RACE_LAP_CALL% | Pilot/time for fastest lap in race (with prompt) |
| %FASTEST_RACE_SPEED% | Pilot/speed for fastest speed in race |
| %FASTEST_RACE_SPEED_CALL% | Pilot/speed for fastest speed in race (with prompt) |
| %WINNER% | Pilot callsign for winner of race |
| %WINNER_CALL% | Pilot callsign for winner of race (with prompt) |
| %PREVIOUS_WINNER% | Pilot callsign for winner of previous race |
| %PREVIOUS_WINNER_CALL% | Pilot callsign for winner of previous race (with prompt) |
| %PILOTS% | List of pilot callsigns (read out slower) |
| %LINEUP% | List of pilot callsigns (read out faster) |
| %FREQS% | List of pilot callsigns and frequency assignments |
| %LEADER% | Callsign of pilot currently leading race |
| %LEADER_CALL% | Callsign of pilot currently leading race, in the form "NAME is leading" |
| %SPLIT_TIME% | Split time for pilot (see [Secondary / Split Timers](../doc/Cluster.md) doc) |
| %SPLIT_SPEED% | Split speed for pilot (see [Secondary / Split Timers](../doc/Cluster.md) doc) |
| %RACE_RESULT% | Race result status message (race winner or co-op result) |
| %COOP_RACE_INFO% | Co-op race mode information (target time or laps) |
| %COOP_RACE_LAP_TOTALS% | Pilot lap counts for race in co-op mode |
| %CURRENT_TIME_AP% | Current time (12-hour clock) |
| %CURRENT_TIME_24% | Current time (24-hour clock) |
| %CURRENT_TIME_SECS_AP% | Current time, with seconds (12-hour clock) |
| %CURRENT_TIME_SECS_24% | Current time, with seconds (24-hour clock) |
| %DELAY_#_SECS% | Delay voice callout by given number of seconds |
| %PILOTS_INTERVAL_#_SECS%  | List of callsigns separated by interval seconds (must be only variable) |

#### LED Effects
Choose a visual effect for each timer event. The timer will display this effect when the event occurs, immediately overriding any existing display or effect. Some visual effects are only available on particular timer events. Some visual effects are modified by the event, most notably the color of gate crossing enters/exits. Most effects can be previewed through the LED Control panel.

Some LED effects can be delayed a short time if the timer is busy with time-critical tasks. (Others such as race start are never delayed.) Because of this effect and potentially concurrent crossings, _"Turn Off"_ should usually be avoided for gate exits. Instead, use _"No Change"_ on gate entrance and your desired effect on gate exit.

_This section will not appear if your timer does not have LEDs configured. A notice appears in the startup log._

#### LED Control
This section will override the current LED display. Choose to temporarily shut off the display, display some pre-configured colors, display any custom color, or display a defined effect. You can also use the slider to adjust the brightness of your panel. The ideal setting for FPV cameras is where the lit panel matches the brightness of a white object. This puts the panel output within the dynamic range of what the camera can capture. However, using a low brightness setting distorts color reproduction and smoothness of color transitions.

_This section will not appear if your timer does not have LEDs configured. A notice appears in the startup log._

#### System
Choose the interface language, and change parameters that affect the appearance of the timer such as its name and color scheme. You can also shut down the server from here.

#### Status
Provides information about sensors and the timer cluster (secondary/split and mirror timers). A _reconnect_ button appears here if cluster timer communications fail and RotorHazard cannot automatically recover.

### Run

This page allows you to control the timer and run races.

Select the Heat for the race which is to be run next.

Start the race when ready. (Hotkey: <kbd>z</kbd>) The timer will do a quick communication to the server to  compensate for client/server response time, then begin the staging procedure defined by the current race format.

Tuning parameters can be adjusted here by clicking on/touching any of the graphs for each node. See [doc/Tuning Parameters.md](Tuning%20Parameters.md) for a detailed description and tuning guide.

During the race, there is an "×" next to each counted lap. This will discard that lap pass, so its time is moved to the next lap. Use this to remove errant extra passes, or clean up pilots flying close to the start gate after their race finished.

Pressing the "+ Lap" button will manually trigger a lap pass for that node.

When a race is over, use the "Stop Race" button (Hotkey: <kbd>x</kbd>) to discontinue counting laps. You need to do this  even if the timer reaches zero in a "Count Down" format—a popular race format allows pilots to finish the lap they are on when time expires. For best results, clear the timing gate and allow all valid crossings to end before stopping the race.

Once a race has concluded, you must choose "Save Laps" or "Discard Laps" before starting another race. "Save Laps" (Hotkey: <kbd>c</kbd>) will store race results to the database and display them on the "Results" page. "Discard Laps" (Hotkey: <kbd>v</kbd>) will discard the race results. Saving laps will automatically advance the heat selection to the next heat with the same class as the saved race.

(The spacebar can also be used as a hotkey for the Start, Stop and Save functions.)

The Race Management panel provides quick access to change the current Race Format, Profile, Minimum Lap Time, or Team/Co-op Racing Mode. _Audio Control_ and _LED Control_ are the same as the Settings page. The History Export dumps a CSV file to be downloaded of the recorded RSSI values in the most recently completed race. "Time Until Race Start" will schedule a race to be run at a future time. Operators may use this to set a hard limit on the amount of time allowed for pilots to prepare, or to start the timer and then participate in the race themselves.

The Callout panel may be used to configure voice callouts, which can be triggered by clicking on the "play" button or hitting the associated hot-key sequence.  (For instance, hitting Ctl+Alt+1 will trigger the first voice callout.)  Many of the variables listed under "Event Actions" may be used on these callouts.

### Marshal

Adjust results of saved races.

Select the round, heat, and pilot to adjust. Enter and Exit points are automatically loaded from the saved race data. Adjust the Enter and Exit points to recalibrate the race after the fact. "Load from Node" to copy current live calibration data over the active values. "Save to Node" to copy the active values over the current live values. "Recalculate Race" to use the active Enter/Exit values as calibration points for a "re-run" of the race. This will erase current laps and replace them with the recalculated information. Manually entered laps are preserved.

Add laps by entering the crossing time in seconds from the beginning of the race, then pressing the "Add Lap" button.

Delete laps with the "×" button on the unwanted lap. Deleted laps are removed from calculations but remain present in the data for later reference. "Discard Laps" to permanently remove the data from the database.

You may click on/touch the graph to set enter/exit points, activate recalculation, and highlight specific laps. Clicking on laps in the list also adds a highlight on the graph. Press <kbd>delete</kbd> or <kbd>x</kbd> to delete a highlighted lap. Active laps are displayed in green, and deleted laps change to red. The width of the lap indicator shows the enter/exit points, and the yellow highlight draws a line at the exact lap time within that window.

"Commit changes" when you are finished adjusting the race data to save it to the database and update the race results.

<br/>

-----------------------------

See Also:<br/>
[doc/Tuning Parameters.md](Tuning%20Parameters.md)<br/>
[doc/Software Setup.md](Software%20Setup.md)<br/>
[doc/Hardware Setup.md](Hardware%20Setup.md)<br/>
[Build Resources (PCB, etc) &#10132;&#xFE0E;](https://github.com/RotorHazard/RotorHazard/tree/main/resources/README.md)

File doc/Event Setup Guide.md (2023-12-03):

# Event Setup Guide

The basics of running an event are:
- Assign frequencies
- Add pilots
- Add heats and classes
- Run races

## Set Frequencies
Choose which set of frequencies you will use for the event. From `Settings`, open `Frequency Setup`. Select a frequency for each seat and set unused seats to *Disabled*.

## Clear Existing Data (if needed)
From `Format`, open `Data Management`. Use the options here to reset or remove outdated information.

## Add Event Details (optional)
From `Format`, open the `Event` panel. Update the Event Name and Description.

- Event information is public and appears on the `Event` page

## Add Pilots
From `Format`, open `Pilots` panel. Add an entry for each pilot participating. Give each pilot a *Callsign* to identify them.

- Callsigns are the primary pilot identifier and appear in most places
- Pilot names appear on the `Event` page and in heat selection boxes
- Phonetic can be used to change how the timer text-to-speech engine announces a pilot; it is never shown visually

## Create Race Formats (optional)
From `Format`, open `Race Formats`. [Adjust the settings](User%20Guide.md#race-format) or create new formats to match your group's preferred settings.

## Add Heats and Classes
**Classes** are groups of heats, such as phases of the event, (like qualifying and finals,) or differing skill groups. When a race is saved, the results for the class will be calculated separately and grouped together as their own section within the race results. It is recommended to create a class for your pre-race practice sessions.

- If a race format is assigned to a class, it is enforced for all races within the class
- Classes will lock after a race has been saved

**Heats** are pilots flying together at exactly the same time. Create heats for each group of pilots. Select which pilots will fly together and add them to a heat slot. Seeded heats can be accomplished by changing the input type to "Heat" or "Class" and selecting the appropriate data source. Use "Auto Frequency" to have RotorHazard assign frequencies instead of making manual selections.

- Heats will lock after a race has been saved
- If pilot frequency assignments change after a race has run, create a new heat—do not modify a locked heat except to correct a mistake

## Run Race
Switch to the `Run` page. Find the appropriate heat in the dropdown. Use the "Start Race" button to begin a race. Race rounds are created automatically as races are run.

- Be sure to select the appropriate heat; "Practice mode" races are pilotless and cannot be saved

## Confirm
Save the race when it concludes. Use the `Marshal` page to [tune the timer](Tuning%20Parameters.md) for each pilot. Future races will self-calibrate using this data.

- Results become visible on the `Results` page.

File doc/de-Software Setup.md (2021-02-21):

# Anweisungen zur Software-Einrichtung

Die zentrale Softwarekomponente des RotorHazard-Systems ist der in Python geschriebene Server, der seine Funktionen ausführt und Webseiten für Browser bereitstellt. In einem Standard-Setup wird der Server auf einem RaspberryPi ausgeführt. (Es ist auch möglich, RotorHazard auf anderen Hardwaretypen auszuführen - siehe Abschnitt [Andere Betriebssysteme](#otheros) weiter unten.)

## System installieren (Raspberry Pi)

Hinweis: Für viele der folgenden Setup-Befehle muss der Rasperry Pi über einen Internetzugang verfügen.

Beginnen Sie mit der Installation von Raspbian und befolgen Sie die offiziellen Anweisungen hier: https://www.raspberrypi.org/downloads/raspbian/. Sie können entweder Desktop oder Lite verwenden.

Konfigurieren Sie die Schnittstellenoptionen auf dem Raspberry Pi.
Öffnen Sie ein Terminalfenster und geben Sie den folgenden Befehl ein:

```
sudo raspi-config
```

Wählen Sie Schnittstellenoptionen und aktivieren Sie: SSH, SPI und I2C.

Führen Sie ein Systemupdate und -upgrade durch (dies kann einige Minuten dauern):

```
sudo apt-get update && sudo apt-get upgrade
```

Installieren Sie Python und die Python-Treiber für das GPIO.

```
sudo apt install python-dev libffi-dev python-smbus build-essential python-pip git scons swig python-rpi.gpio
```

Installieren Sie die Funktionsoberfläche in Python

```
sudo pip install cffi
```

Aktualisieren Sie die i2c-Baudrate

```
sudo nano /boot/config.txt
```

Fügen Sie am Ende der Datei die folgenden Zeilen hinzu:

```
dtparam=i2c_baudrate=75000
core_freq=250
```

Hinweis: In der ersten Zeile wird die Übertragungsrate auf dem I2C-Bus festgelegt (der zur Kommunikation mit den Arduino-Knotenprozessoren verwendet wird). Die zweite Zeile behebt ein potenzielles Problem mit variabler Taktrate, das [hier](https://www.abelectronics.co.uk/kb/article/1089/i2c--smbus-and-raspbian-stretch-linux) beschrieben wird. Wenn ein Raspberry Pi 4 verwendet wird, muss möglicherweise die zweite Zeile weggelassen werden.

Speichern und beenden Sie die Datei mit Strg-X

Installieren Sie den RotorHazard-Code unter '/home/pi/' auf dem Raspberry Pi wie folgt: Gehen Sie zur [Seite mit der neuesten Version](https://github.com/RotorHazard/RotorHazard/releases/latest) für das Projekt und notieren Sie das Versionscode. Ersetzen Sie in den folgenden Befehlen die beiden Vorkommen von "1.2.3" durch den aktuellen Versionscode und geben Sie die folgenden Befehle ein:

```
cd ~
wget https://codeload.github.com/RotorHazard/RotorHazard/zip/1.2.3 -O temp.zip
unzip temp.zip
mv RotorHazard-1.2.3 RotorHazard
rm temp.zip
```

Installieren Sie die RotorHazard-Serverabhängigkeiten (haben Sie etwas Geduld, dieser Befehl kann einige Minuten dauern):

```
cd ~/RotorHazard/src/server
sudo pip install -r requirements.txt
```

Aktualisieren Sie die Berechtigungen im Arbeitsordner:

```
cd ~/RotorHazard/src
sudo chmod 777 server
```

*Hinweis: Wenn RotorHazard bereits installiert ist, lesen Sie den folgenden Abschnitt [Aktualisieren einer vorhandenen Installation](#update).*

## Installieren Sie den Code für Empfängerknoten (Arduinos).

Arduino 1.8+ ist erforderlich. Download von https://www.arduino.cc/en/Main/Software

*Der Knotencode und die Serverversion müssen übereinstimmen. Verwenden Sie den 'Knoten'-Code, der in dem zuvor heruntergeladenen Servercode enthalten ist. Laden Sie keine andere Datei direkt von GitHub herunter.*

Der Knotencode kann mit der [Eclipse IDE](https://www.eclipse.org/eclipseide/) und der "[Eclipse C ++ - IDE für Arduino](https://marketplace.eclipse.org/content) bearbeitet und erstellt werden / eclipse-c-ide-arduino) "Plugin (oder die altmodische Methode mit der Arduino IDE). In Eclipse kann das Knotencode-Projekt über "Datei | Projekte aus Dateisystem öffnen ..." geladen werden.

Wenn Sie keine RotorHazard-Platine verwenden, bearbeiten Sie die Datei 'src/node/config.h' und konfigurieren Sie vor dem Hochladen den Wert '#define NODE_NUMBER' für jeden Knoten. Für den ersten Knoten setzen Sie NODE_NUMBER auf 1, für den zweiten auf 2 usw.

```
// Node Setup -- Set node number here (1 - 8)
#define NODE_NUMBER 1
```

Die Auswahl der Hardwareadresse ist auch möglich, indem die Hardwarestifte gemäß der [veröffentlichten Spezifikation](https://github.com/RotorHazard/RotorHazard/wiki/Specification:-Node-hardware-addressing) geerdet werden.

## Installieren Sie optionale Komponenten

### Echtzeituhr

Durch die Installation eines Echtzeituhrmoduls kann der RotorHazard-Timer das korrekte Datum und die korrekte Uhrzeit beibehalten, auch wenn keine Internetverbindung verfügbar ist. Weitere Informationen finden Sie unter '[doc/Real Time Clock.md](de-Real%20Time%20Clock.md)'.

### WS2812b LED-Unterstützung

Die ws2812b-Steuerelemente werden von folgendem Projekt bereitgestellt:

[https://github.com/jgarff/rpi_ws281x](https://github.com/jgarff/rpi_ws281x)

Klonen Sie das Repository auf den Pi und starten Sie Scons:

```
cd ~
sudo git clone https://github.com/jgarff/rpi_ws281x.git
cd rpi_ws281x
sudo scons
```

Installieren Sie die Python-Bibliothek:

```
cd python
sudo python setup.py install
```

Hinweis: Der Wert **LED_COUNT** muss in der Datei `src/server/config.json` festgelegt werden. Die Standardkonfiguration der LED-Einstellungen finden Sie in der Datei "src/server/config-dist.json". Folgende Elemente können eingestellt werden:

```
LED_COUNT:  Anzahl der LED-Pixel im Streifen (oder Panel)
LED_PIN:  GPIO-Pin mit den Pixeln verbunden (Standard 10 verwendet SPI '/dev/spidev0.0')
LED_FREQ_HZ:  LED-Signalfrequenz in Hertz (normalerweise 800000)
LED_DMA:  DMA-Kanal zur Signalerzeugung (Standard 10)
LED_INVERT:  True, um das Signal zu invertieren (bei Verwendung der NPN-Transistorpegelverschiebung)
LED_CHANNEL:  Setzen Sie für die GPIOs 13, 19, 41, 45 oder 53 auf '1'
LED_STRIP:  Streifentyp und Farbreihenfolge (Standard ist 'GRB')
LED_ROWS:  Anzahl der Zeilen im LED-Panel-Array (1 für Streifen)
PANEL_ROTATE:  Optionaler Panel-Rotationswert (Standard 0)
INVERTED_PANEL_ROWS:  Optionale Panel-Zeilenumkehrung (Standardwert false)
```

Falls angegeben, muss der Wert **LED_STRIP** einer der folgenden Werte sein: 'RGB', 'RBG', 'GRB', 'GBR', 'BRG', 'BGR', 'RGBW', 'RBGW', 'GRBW' , 'GBRW', 'BRGW', 'BGRW'

Die LED-Bibliothek erfordert direkten Speicher und GPIO-Zugriff. Wenn aktiviert, muss RotorHazard mit `sudo` ausgeführt werden.

```
sudo python server.py
```

### INA219 Spannungs- / Stromunterstützung

Die ina219-Schnittstelle wird von folgendem Projekt bereitgestellt:

https://github.com/chrisb2/pi_ina219

Klonen Sie das Repository auf den Pi:

```
cd ~
sudo git clone https://github.com/chrisb2/pi_ina219.git
cd pi_ina219
```

Installieren Sie die Python-Bibliothek:

```
sudo python setup.py install
```

### BME280 Temperaturunterstützung

Die bme280-Schnittstelle wird von folgendem Projekt bereitgestellt:
https://github.com/rm-hull/bme280

Klonen Sie das Repository auf den Pi:

```
cd ~
sudo git clone https://github.com/rm-hull/bme280.git
cd bme280
```

Installieren Sie die Python-Bibliothek:

```
sudo python setup.py install
```

### Java-Unterstützung

Java ermöglicht die Berechnung von IMD-Scores. Wenn Sie mit RASPBIAN MIT GRAFISCHER OBERFLÄCHE begonnen haben, sollte dieser Schritt nicht erforderlich sein, da Java standardmäßig installiert ist. Andernfalls:

```
sudo apt install default-jdk-headless
```

## System vorbereiten

### System neu starten

Nachdem die obigen Einrichtungsschritte ausgeführt wurden, sollte das System neu gestartet werden, indem folgendes eingegeben wird:

```
sudo reboot
```

### System starten

Die folgenden Anweisungen starten den Webserver auf dem Himbeer-Pi und ermöglichen die vollständige Kontrolle und Konfiguration des Systems, um Rennen durchzuführen und Rundenzeiten zu sparen.

#### Manueller Start

Öffnen Sie ein Terminal und geben Sie folgendes ein:

```
cd ~/RotorHazard/src/server
python server.py
```

Der Server kann durch Drücken von Strg-C gestoppt werden

#### Automatischer Start beim Hochfahren

So konfigurieren Sie das System so, dass der RotorHazard-Server beim Hochfahren automatisch gestartet wird:

Erstellen Sie eine Servicedatei:

```
sudo nano /lib/systemd/system/rotorhazard.service
```

mit folgenden Inhalten

```
[Unit]
Description=RotorHazard Server
After=multi-user.target

[Service]
WorkingDirectory=/home/pi/RotorHazard/src/server
ExecStart=/usr/bin/python server.py

[Install]
WantedBy=multi-user.target
```

Speichern und beenden (STRG-X, Y, ENTER).

Berechtigungen anpassen:

```
sudo chmod 644 /lib/systemd/system/rotorhazard.service
```

Aktivieren Sie den Dienst:

```
sudo systemctl daemon-reload
sudo systemctl enable rotorhazard.service
sudo reboot
```

#### Beenden des Serverdienstes

Wenn der RotorHazard-Server während des Startvorgangs als Dienst gestartet wurde, kann er mit einem Befehl wie dem folgenden gestoppt werden:

```
sudo systemctl stop rotorhazard
```

Geben Sie Folgendes ein, um den Dienst zu deaktivieren (damit er beim Systemstart nicht mehr ausgeführt wird):

```
sudo systemctl disable rotorhazard.service
```

### System herunterfahren

Ein Herunterfahren des Systems sollte immer durchgeführt werden, bevor der Netzstecker gezogen wird, indem Sie entweder auf der Seite "Einstellungen" auf die Schaltfläche "Herunterfahren" klicken oder Folgendes in ein Terminal eingeben:

```
sudo shutdown now
```

### Aktualisieren einer vorhandenen Installation

Vor dem Update sollte jeder aktuell ausgeführte RotorHazard-Server gestoppt werden. Wenn es als Dienst installiert ist, kann es mit einem Befehl wie dem folgenden gestoppt werden:

```
sudo systemctl stop rotorhazard
```

So aktualisieren Sie eine vorhandene RotorHazard-Installation: Gehen Sie zur Seite [Neueste Version](https://github.com/RotorHazard/RotorHazard/releases/latest) für das Projekt und notieren Sie den Versionscode. Ersetzen Sie in den folgenden Befehlen die beiden Vorkommen von "1.2.3" durch den aktuellen Versionscode und geben Sie die folgenden Befehle ein:

```
cd ~
wget https://codeload.github.com/RotorHazard/RotorHazard/zip/1.2.3 -O temp.zip
unzip temp.zip
mv RotorHazard RotorHazard.old
mv RotorHazard-1.2.3 RotorHazard
rm temp.zip
cp RotorHazard.old/src/server/config.json RotorHazard/src/server/
cp RotorHazard.old/src/server/database.db RotorHazard/src/server/
```

Die vorherige Installation landet im Verzeichnis 'RotorHazard.old', das gelöscht oder verschoben werden kann.

Die RotorHazard-Serverabhängigkeiten sollten ebenfalls aktualisiert werden (haben Sie etwas Geduld, dieser Befehl kann einige Minuten dauern):

```
cd ~/RotorHazard/src/server
sudo pip install --upgrade --no-cache-dir -r requirements.txt
```

### Aktivieren Sie die Portweiterleitung

Der RotorHazard-Server verwendet standardmäßig Port 5000, da dies für einige Integrationen von Drittanbietern erforderlich ist. Während Sie den Port über `HTTP_PORT` in der Datei `config.json` ändern können, besteht ein besserer Ansatz häufig darin, den Web-Standardport von 80 bis 5000 weiterzuleiten.

Standardmäßig verwendet HTTP Port 80. Für andere Werte muss der Port als Teil der in Client-Browsern eingegebenen URL enthalten sein. Wenn andere Webdienste auf dem Pi ausgeführt werden, wird Port 80 möglicherweise bereits verwendet, und die Wiederverwendung führt zu Problemen. Wenn Port 80 direkt über `HTTP_PORT` verwendet wird, muss der Server möglicherweise mit dem Befehl *sudo* ausgeführt werden. Mit den folgenden Befehlen wird der Server auf Port 5000 ausgeführt, aber das System sendet den Datenverkehr von Port 80 an Port 80.

```
sudo iptables -A PREROUTING -t nat -p tcp --dport 80 -j REDIRECT --to-ports 5000
sudo iptables-save
sudo apt-get install iptables-persistent
```

Nach dem Ausführen dieser Befehle ist RotorHazard an beiden Ports 80 und 5000 verfügbar. Wenn es an Port 80 verfügbar ist, können Sie den Port beim Zugriff auf den Server deaktivieren: `http://127.0.0.1`
<br/>

---

### Andere Betriebssysteme

Der RotorHazard-Server kann auf jedem Computer mit einem Betriebssystem ausgeführt werden, das Python unterstützt. In diesen alternativen Konfigurationen können ein oder mehrere Hardwareknoten über USB verbunden sein. Weitere Informationen finden Sie unter [doc/USB Nodes.md](de-USB%20Nodes.md). Der Server kann auch mit simulierten (Schein-) Knoten ausgeführt werden.

So installieren Sie den RotorHazard-Server auf diesen Systemen:

1. Wenn auf dem Computer Python noch nicht installiert ist, laden Sie Python Version 2.7 von https://www.python.org/downloads herunter und installieren Sie es. Um zu überprüfen, ob Python installiert ist, öffnen Sie eine Eingabeaufforderung und geben Sie ```python --version``` ein
2. Laden Sie von RotorHazard [Veröffentlichungsseite auf github](https://github.com/RotorHazard/RotorHazard/releases) die Datei "Quellcode (zip)" herunter.
3. Entpacken Sie die heruntergeladene Datei in ein Verzeichnis (auch bekannt als Ordner) auf dem Computer.
4. Öffnen Sie eine Eingabeaufforderung und navigieren Sie zum Verzeichnis `src/server` in den RotorHazard-Dateien (mit dem Befehl 'cd').
5. Installieren Sie die RotorHazard-Serverabhängigkeiten mithilfe der Datei 'requirements.txt' mit einem der folgenden Befehle (Beachten Sie, dass für diesen Befehl möglicherweise Administratorzugriff auf den Computer erforderlich ist und der Befehl einige Minuten dauern kann):

* Auf einem Windows-System lautet der zu verwendende Befehl wahrscheinlich:<br/>```python -m pip install -r requirements.txt```<br/><br/>
* Auf einem Linux-System lautet der zu verwendende Befehl wahrscheinlich:<br/>```sudo pip install -r requirements.txt```<br/>

So führen Sie den RotorHazard-Server auf diesen Systemen aus:

1. Öffnen Sie eine Eingabeaufforderung und navigieren Sie zum Verzeichnis `src/server` in den RotorHazard-Dateien (falls nicht bereits vorhanden).
2. Geben Sie ```python server.py``` ein.
3. Wenn der Server ordnungsgemäß gestartet wird, sollten verschiedene Protokollmeldungen angezeigt werden, darunter eine wie folgt:

   ```
   Running http server at port 5000
   ```
4. Der Server kann durch Drücken von Strg-C gestoppt werden

Wenn Hardwareknoten über USB verbunden sind, müssen sie im Abschnitt `SERIAL_PORTS` in der Konfigurationsdatei "src/server/config.json" konfiguriert werden (siehe [doc/USB Nodes.md](de-USB%20Nodes.md) für Details).

Wenn keine Hardwareknoten konfiguriert sind, arbeitet der Server mit simulierten (Schein-) Knoten. In diesem Modus kann die Web-GUI-Oberfläche untersucht und getestet werden.

Um die Web-GUI-Oberfläche anzuzeigen, öffnen Sie einen Webbrowser und geben Sie in die Adressleiste Folgendes ein: `localhost:5000` (Wenn der HTTP_PORT-Wert in der Konfiguration geändert wurde, verwenden Sie diesen Wert anstelle von 5000). Wenn der Server ausgeführt wird, sollte die RotorHazard-Hauptseite angezeigt werden. Beachten Sie, dass für den Rennleiter reservierte Seiten (Admin / Einstellungen) mit dem in der Konfiguration angegebenen Benutzernamen und Passwort passwortgeschützt sind.
<br/>

---

### Protokollierung

Der RotorHazard-Server generiert "Protokoll" -Nachrichten mit Informationen zu seinen Vorgängen. Unten finden Sie eine Beispielkonfiguration für die Protokollierung:

```
    "LOGGING": {
        "CONSOLE_LEVEL": "INFO",
        "SYSLOG_LEVEL": "NONE",
        "FILELOG_LEVEL": "INFO",
        "FILELOG_NUM_KEEP": 30,
        "CONSOLE_STREAM": "stdout"
    }
```

Die folgenden Protokollstufen können angegeben werden: DEBUG, INFO, WARNING, WARN, ERROR, FATAL, CRITICAL, NONE

Wenn der Wert FILELOG_LEVEL nicht NONE ist, generiert der Server Protokolldateien im Verzeichnis `src/server/logs`. Bei jedem Start des Servers wird eine neue Protokolldatei erstellt, wobei jede Datei einen eindeutigen Namen hat, der auf dem aktuellen Datum und der aktuellen Uhrzeit basiert (d. H. "Rh_20200621_181239.log"). Wenn Sie FILELOG_LEVEL auf DEBUG setzen, werden detailliertere Protokollmeldungen in der Protokolldatei gespeichert. Dies kann beim Debuggen von Problemen hilfreich sein.

Der Wert FILELOG_NUM_KEEP gibt die Anzahl der zu speichernden Protokolldateien an. Der Rest wird gelöscht (älteste zuerst).

Der CONSOLE_STREAM-Wert kann "stdout" oder "stderr" sein.

Wenn der Wert SYSLOG_LEVEL nicht NONE ist, sendet der Server Protokollnachrichten an das im Host-Betriebssystem integrierte Protokollierungsdienstprogramm.

Das aktuelle Serverprotokoll wird möglicherweise über den Eintrag "Serverprotokoll anzeigen" im Dropdown-Menü angezeigt. Das angezeigte Protokoll ist "live", da es aktualisiert wird, wenn neue Nachrichten generiert werden. Das Protokoll kann in einem separaten Fenster angezeigt werden, indem Sie mit der rechten Maustaste auf den Menüpunkt "Serverprotokoll anzeigen" klicken und die Option "Link in neuem Fenster öffnen" (oder ähnlich) auswählen.

Durch Klicken auf die Schaltfläche "Text auswählen" wird der gesamte angezeigte Protokolltext ausgewählt, der dann kopiert und eingefügt werden kann. Durch Klicken auf die Schaltfläche "Protokolle herunterladen" wird eine ZIP-Archivdatei erstellt und heruntergeladen, die alle verfügbaren Protokolldateien sowie die aktuellen Konfigurations- und Datenbankdateien enthält. Die '.zip'-Archivdatei kann auch generiert werden, indem der Server mit dem folgenden Befehl ausgeführt wird: `python server.py --ziplogs`

Wenn Sie Probleme melden, wird dringend empfohlen, die Schaltfläche "Protokolle herunterladen" zu verwenden und die generierte ZIP-Datei einzuschließen.

<br/>

---

Siehe auch:
[doc/Hardware Setup.md](de-Hardware%20Setup.md)<br/>
[doc/USB Nodes.md](de-USB%20Nodes.md)<br/>
[doc/User Guide.md](de-User%20Guide.md)

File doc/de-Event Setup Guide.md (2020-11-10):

# Anleitung zur Ereigniseinrichtung

Die Grundlagen des Aufbaus einer Veranstaltung sind die Einrichtung von Piloten, Läufen und Knotenpunkten. Sie können auch Veranstaltungsdetails und Rennklassen hinzufügen, wenn Sie dies wünschen.

## Vorhandene Daten löschen (falls erforderlich)

Öffnen Sie unter Einstellungen die Datenbank. Verwenden Sie die Optionen hier, um veraltete Informationen aus der Datenbank zu entfernen.

## Ereignisdetails hinzufügen (optional)

Öffnen Sie unter Einstellungen das Ereignis-Panel. Aktualisieren Sie den Ereignisnamen und die Beschreibung. Diese werden auf der Startseite angezeigt, wenn Benutzer den Timer zum ersten Mal besuchen. Lassen Sie die Piloten wissen, was sie während der Veranstaltung erwartet, z.B. das Veranstaltungsformat und den Zeitplan.

## Piloten hinzufügen

Öffnen Sie unter Einstellungen das Panel Piloten. Fügen Sie für jeden teilnehmenden Piloten einen Eintrag hinzu. Der Name des Piloten wird auf der Veranstaltungsseite angezeigt; das Rufzeichen wird für die Anzeige der Rennergebnisse und für Sprachanrufe verwendet. Testen Sie die Sprachaussprache mit der Schaltfläche ">". Falls gewünscht, schreiben Sie eine phonetische Schreibweise. Diese wird nie angezeigt, wird aber zur Aussprache des Rufzeichens verwendet.

## Rennformate erstellen (optional)

Öffnen Sie unter Einstellungen die Rennformate. Passen Sie die [Einstellungen](de-User%20Guide.md#race-format) an oder erstellen Sie neue Formate, damit sie die Art der Startaufstellung Ihrer Gruppe, die Siegbedingungen usw. ändern können.

## Läufe und Klassen hinzufügen

**Läufe** sind Piloten, die zusammen zur genau gleichen Zeit fliegen. Benennen Sie Ihren Lauf, oder lassen Sie den Namen leer, um einen Standardnamen zu verwenden. Wählen Sie aus, welche Piloten genau zur gleichen Zeit fliegen, und fügen Sie sie zu einem Lauf hinzu. Die Anzahl der verfügbaren Lauf-Plätze wird durch die Anzahl der mit dem Timer verbundenen Knoten bestimmt. Verwenden Sie "Keine" für unbenutzte Lauf-Plätze.

**Klassen** sind Gruppen von Piloten mit gemeinsamen Eigenschaften. Wenn Sie mehr als eine Klasse benötigen, erstellen Sie Klassen, die darauf basieren, wie Ihre Veranstaltung strukturiert ist. Benennen Sie Ihre Klasse als Referenz an anderer Stelle. Die Klassenbeschreibung ist auf der Seite Veranstaltung sichtbar. Die Einstellung eines optionalen Formats zwingt alle Rennen innerhalb dieser Klasse, die gewählten Einstellungen für das Rennformat zu verwenden.

Weisen Sie den Klassen Läufe zu, um sie zu verwenden. Wenn ein Rennen für einen Lauf mit einer zugewiesenen Klasse gespeichert wird, werden die Ergebnisse für die Klasse separat berechnet und erscheinen als eigener Abschnitt innerhalb der Rennergebnisse.

## Knoten auf Umgebung abstimmen

Sobald der Timer am Rennort läuft, passen Sie die [Knotenparameter und Filtereinstellungen](de-Tuning%20Parameters.md) so an, dass sie der gewünschten Rennart am besten entsprechen. Optional können Sie ein Profil für diesen Ort erstellen, damit Sie es später leicht wieder laden können.

## Beispiel

8 Piloten werden sich zu einem Indoor-Micro-Quad-Rennen versammeln. Das Veranstaltungsformat besteht aus fünf Qualifikationsrunden, in denen die Gesamtrundenzahl zusammengezählt wird, wobei die vier besten Piloten in einen einzigen Endlauf aufsteigen. Vor der Veranstaltung addiert der Organisator alle Piloten in der Pilotenliste. Es werden zwei Klassen geschaffen, "Qualifying" und "Final", und beiden Klassen wird das Rennformat "Whoop Sprint" zugewiesen. Es werden zwei Läufe mit jeweils vier Piloten erstellt, und beide Läufe werden der Klasse "Qualifying" zugeordnet.

Am Tag der Veranstaltung wählt der Organisator das "Indoor"-Profil, um die gewünschten Frequenzen und Filtereinstellungen festzulegen, und stellt sicher, dass die Knoten richtig abgestimmt sind. Auf der Seite "Rennen" werden die Läufe jeweils fünf Mal durchgeführt. Der Zeitnehmer organisiert diese Läufe in die Runden 1 bis 5 für die Ergebnisseite, während die Läufe durchgeführt werden.

Nachdem die Qualifikations-Läufe beendet sind, überprüft der Veranstalter die Ergebnisseite und überprüft die "Qualifying"-Klasse, um die besten Piloten zu ermitteln. Der Organisator öffnet die Seite "Einstellungen" und das Panel "Vorläufe", erstellt einen neuen Lauf und weist ihm die vier besten Piloten zu, dann weist er dem Lauf die Klasse "Finale" zu. Das Rennen für diesen letzten Lauf wird durchgeführt. Auf der Ergebnisseite hält die Klasse "Final" die Ergebnisse des Finales und zeigt sie getrennt von den anderen an.

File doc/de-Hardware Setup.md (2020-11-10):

# Anweisungen zur Hardware-Einrichtung

## Stückliste

### Empfänger-Knoten (diese Liste ergibt einen Knoten, bis zu acht)

* 1 x [Arduino Nano](https://www.ebay.com/sch/i.html?_nkw=Arduino+Nano+V3.0+16M+5V+ATmega328P)
* 1 x [RX5808 Modul](https://www.banggood.com/search/rx5808-module.html) mit SPI mod (Module mit Datumscode 20120322 funktionieren bekanntermaßen)
* 3 x 1k-Ohm-Widerstand
* 1 x 100k-Ohm-Widerstand
* 26 AWG und 30 AWG Silikondraht

### Systemkomponenten

* 1 x Raspberry Pi3 (Pi2-Benutzer haben Probleme mit mehreren angeschlossenen Knoten gemeldet)
* 8 GB (Minimum) Micro-SD Karte
* 26 AWG und 30 AWG Silikonkabel (für die Verdrahtung zu jedem Empfängerknoten)
* 3D gedrucktes Gehäuse zur Aufnahme der Elektronik
* 5V-Stromversorgung, mindestens 3 Ampere (oder 12V-Stromversorgung, wenn bordeigene Regler verwendet werden)

### Zusätzliche Komponenten

* [HF-Abschirmung](de-Shielding%20and%20Course%20Position.md)

### Optionale Komponenten

* Ethernet-Kabel, 15 Meter plus
* Stromkabel für den Außenbereich, 15 Meter plus
* Netzwerk-Router
* Laptop/Tablett
* ws2812b LEDs

## Hardware-Einrichtung

### RX5808 Video-Empfänger

Stellen Sie sicher, dass Ihre Empfänger SPI unterstützen. *Wenn dies nicht der Fall ist, modifizieren Sie die RX5808-Empfänger wie folgt, um die SPI-Unterstützung zu aktivieren*. Die meisten heute erhältlichen RX5808-Module werden bereits mit aktiviertem SPI geliefert:

Entfernen Sie die Abschirmung vom RX5808, die Abschirmung wird normalerweise durch ein paar Lötpunkte an den Kanten gehalten. Verwenden Sie etwas Lötlotdocht, um das Lot zu entfernen und die Abschirmung vom Empfänger zu befreien. Achten Sie darauf, keine Massepads auf dem Empfänger zu beschädigen. In der Regel befinden sich am Rand kleine Löcher, mit denen Sie die Abschirmung leichter entfernen können.

Entfernen Sie den folgenden Widerstand:
RX5808 spi mod

Die Abschirmung sollte nach Entfernen des Widerstandes wieder angelötet werden.

### Empfänger-Knoten

Vollständige Verkabelung der Verbindungen zwischen jedem Arduino und RX5808.
Verdrahtung des Empfängerknotens

Hinweis: Ein einfacher Empfängerknoten kann auch über USB konstruiert und angeschlossen werden -- siehe [doc/USB Nodes.md](de-USB%20Nodes.md).

### System-Baugruppe

Vollständige Verkabelung der Verbindungen zwischen jedem Arduino und der Raspberry Pi.

Hinweis: Vergewissern Sie sich, dass alle Empfänger-Knoten und die Raspberry Pi an eine gemeinsame Masse angeschlossen sind; wenn nicht, können die i2c-Nachrichten beschädigt werden.
Systemverkabelung

### Hinzufügen einer gerichteten RF-Abschirmung

Eine gerichtete HF-Abschirmung verbessert die Fähigkeit des Systems zur Abwehr von Fehlpässen erheblich. Siehe [HF-Abschirmung](de-Shielding%20and%20Course%20Position.md)

### Echtzeituhr

Unter "[doc/Real Time Clock.md](de-Real%20Time%20Clock.md)" finden Sie weitere Informationen über die Installation eines Echtzeituhr-Moduls, mit dem das System das Datum und die Uhrzeit besser verwalten kann.

### WS2812b LED-Unterstützung

Die Stifte im grünen Kasten sind die, die bereits vom Timer verwendet wurden. An den Pins im roten Kasten schließen Sie das Signal und die Masse der ws2812b-LEDs an.  Die LEDs benötigen eine separate Stromquelle. Siehe WS2812b LED-Unterstützung unter [doc/Software Setup.md](de-Software%20Setup.md).

led wiring

### Zusätzliche Sensoren

Sensoren (wie BME280 und INA219) können an den I2C-Bus und die Stromversorgungspins angeschlossen werden. Siehe die '..._sensor.py'-Dateien im Verzeichnis "src/interface" für Implementierungsbeispiele. Die Sensoren müssen in der Datei "src/server/config.json" spezifiziert werden -- in der Beispielkonfiguration unten wird ein BME280-Sensor an I2C-Adresse 0x76 (als "Klima") und INA219-Sensoren an 0x40 und 0x41 konfiguriert.

```
    "SENSOREN": {
            "i2c:0x76": {
                    "Name": "Klima": "Klima".
            },
            "i2c:0x40": {
                    "Name": "Batterie",
                    "max_current": 0.1
            },
            "i2c:0x41": {
                    "Name": "Pi",
                    "max_current": 2
            }
    },
```

### Mehrere Timer

Mehrere RotorHazard Timer können miteinander verbunden werden (d.h. für Split Timing und Spiegelung) -- siehe [doc/Cluster.md](de-Cluster.md).

---

Siehe auch:<br/>
[doc/USB-Knoten.md](de-USB%20Nodes.md)<br/>
[doc/Software Setup.md](de-Software%20Setup.md)<br/>
[doc/Benutzerhandbuch.md](de-User%20Guide.md)

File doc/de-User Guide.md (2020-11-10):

# RotorHazard Race Timer Benutzerhandbuch

## Ersteinrichtung

### Hardware- und Software-Setup

Befolgen Sie die Anweisungen hier, falls dies noch nicht geschehen ist: <br>
[Hardware Setup](de-Hardware%20Setup.md)<br>
[Software Setup](de-Software%20Setup.md)<br>
[RF shielding](de-Shielding%20and%20Course%20Position.md)

### Konfigurationsdatei einrichten

Suchen Sie im Verzeichnis "src / server" nach *config-dist.json* und kopieren Sie es nach *config.json*. Bearbeiten Sie diese Datei und ändern Sie die Werte ADMIN_USERNAME und ADMIN_PASSWORD. Diese Elemente in dieser Datei müssen im gültigen JSON-Format vorliegen. Ein Linter-Dienstprogramm wie [JSONLint](https://jsonlint.com/) kann verwendet werden, um nach Syntaxfehlern zu suchen.

ADMIN_USERNAME und ADMIN_PASSWORD sind die Anmeldeinformationen, die Sie benötigen, um auf die für den Rennleiter reservierten Seiten zuzugreifen (d. H. Auf die Seiten *Einstellungen* und *Ausführen*).

### Stellen Sie eine Verbindung zum Server her

Ein Computer, ein Smartphone oder ein Tablet kann zur Interaktion mit dem Race-Timer verwendet werden, indem ein Webbrowser gestartet und die IP-Adresse des Raspberry Pi eingegeben wird. Der Raspberry Pi kann über ein Ethernet-Kabel oder ein verfügbares WiFi-Netzwerk verbunden werden. Wenn die IP-Adresse des Pi nicht bekannt ist, kann sie mit dem Terminalbefehl "ifconfig" angezeigt und über die "Netzwerkeinstellungen" auf dem Pi-Desktop auf einen statischen Wert konfiguriert werden. Wenn der Pi mit einem WiFi-Netzwerk verbunden ist, finden Sie seine IP-Adresse in der Liste "Clients" auf der Administrationsseite für den Router des Netzwerks.

Geben Sie im Webbrowser die IP-Adresse von für den Race-Timer und den Portwert ein, den Sie in der Konfigurationsdatei festgelegt haben (oder lassen Sie den Port: weg, wenn er auf 80 eingestellt ist).

```
XXX.XXX.XXX.XXX:5000
```

Sobald die Seite erfolgreich angezeigt wurde, kann sie im Browser mit einem Lesezeichen versehen werden. Für den Rennleiter reservierte Seiten ("Admin / Einstellungen") sind mit dem in der Konfigurationsdatei angegebenen Benutzernamen und Passwort passwortgeschützt.

## Seiten

### Home

Auf dieser Seite werden der Name und die Beschreibung des Ereignisses sowie eine Reihe von Schaltflächen für verschiedene andere Seiten angezeigt.

### Veranstaltung

Auf dieser öffentlichen Seite werden das aktuelle Klassen-Setup (falls zutreffend) sowie eine Zusammenfassung der Piloten und ihrer Vorläufe mit Kanalzuweisung angezeigt.

### Ergebnisse

Auf dieser öffentlichen Seite werden Ergebnisse und berechnete Statistiken aller zuvor gespeicherten Rennen angezeigt, die in zusammenklappbaren Feldern organisiert sind. Die Gesamtergebnisse werden für jeden Lauf mit mehreren Runden, jeder Klasse und dem gesamten Ereignis angezeigt.

### Aktuell

Auf dieser Seite werden Informationen zum aktuell laufenden Rennen angezeigt, einschließlich Echtzeit-Rennzeit, Rundenzeiten des Piloten und Rangliste. Es wird automatisch mit dem Ereignis aktualisiert und eignet sich für die Projektion auf einen gut sichtbaren Bildschirm.

Im Abschnitt Audiosteuerung kann der Benutzer auswählen, ob für einen Piloten, alle Piloten oder keine Piloten Runden angekündigt werden sollen. Auf diese Weise kann ein Pilot entscheiden, nur seine eigenen angekündigten Runden zu hören. Ein Benutzer kann auch die Stimme, Lautstärke, Rate und Tonhöhe dieser Ansagen anpassen.

### Einstellungen

Auf dieser Seite können Sie die optionalen Einstellungen und das Ereignis-Setup des Timers ändern.

#### Frequenzeinstellung

Wählen Sie eine Voreinstellung oder wählen Sie die Frequenzen für jeden Knoten manuell aus. Eine beliebige Frequenzauswahl ist möglich, ebenso wie das Deaktivieren eines Knotens. Der IMD-Wert für aktuell ausgewählte Frequenzen wird berechnet und am unteren Rand des Bedienfelds angezeigt.

Profile enthalten Frequenzen und Knotenoptimierungswerte. Durch Ändern dieser Liste wird das ausgewählte Profil sofort aktiviert, und durch Ändern der aktuellen Frequenzen und der Knotenoptimierung wird sofort im Profil gespeichert.

#### Sensor-Tuning

Eine ausführliche Beschreibung und Tuning-Anleitung finden Sie hier [doc/Tuning Parameters.md](de-Tuning%20Parameters.md).

#### Veranstaltung und Klassen

Ereignisinformationen werden auf der Startseite angezeigt, wenn Benutzer zum ersten Mal eine Verbindung zum System herstellen.

Für Veranstaltungen sind keine Klassen erforderlich. Es ist nicht erforderlich, eine Klasse zu erstellen, es sei denn, Sie haben zwei oder mehr in dem Ereignis. Klassen können verwendet werden, um separate Statistiken für Gruppen von Vorläufen zu generieren. Zum Beispiel Open- und Spec-Klassen oder Anfänger- / Pro-Klassen.

#### Vorläufe

Fügen Sie Läufe hinzu, bis genug für alle Piloten vorhanden sind. Falls gewünscht, können optionale Wärmenamen hinzugefügt werden. Heizschlitze können auf *Keine* gesetzt werden, wenn dort kein Pilot zugewiesen ist.

Wenn Sie Klassen verwenden, weisen Sie jede Hitze einer Klasse zu. Stellen Sie sicher, dass für jeden Piloten in jeder Klasse genügend Vorläufe vorhanden sind. Läufe, die einer Klasse zugeordnet sind, sind in einer anderen nicht verfügbar.

Während Sie Rennen laufen, werden die Vorläufe gesperrt und können nicht geändert werden. Dies schützt gespeicherte Renndaten vor Ungültigkeit. Um die Vorläufe erneut zu ändern, öffnen Sie das Bedienfeld *Datenbank* und löschen Sie die Rennen.

#### Piloten

Fügen Sie einen Eintrag für jeden Piloten hinzu, der Rennen fahren wird. Das System kündigt Piloten anhand ihres Rufzeichens an. Eine phonetische Schreibweise für ein Rufzeichen kann verwendet werden, um die Sprachanrufe zu beeinflussen. es ist nicht notwendig.

#### Audiosteuerung

Alle Audiosteuerelemente sind lokal für den Browser und das Gerät, auf dem Sie sie eingestellt haben, einschließlich der Liste der verfügbaren Sprachen, Lautstärken und der verwendeten Ansagen oder Anzeigen.

Sprachauswahl wählt die Text-zu-Sprache-Engine. Die verfügbaren Optionen werden vom Webbrowser und vom Betriebssystem bereitgestellt.

Mit Ankündigungen kann der Benutzer wählen, ob er das Rufzeichen, die Rundennummer und / oder die Rundenzeit jedes Piloten beim Überqueren hören möchte. Die Ankündigung "Race Timer" zeigt perio an, wie viel Zeit verstrichen ist oder noch verbleibt, abhängig vom Timer-Modus im Race-Format. "Team Lap Total" wird nur verwendet, wenn "Team Racing Mode" aktiviert ist.

Sprachlautstärke, Frequenz und Tonhöhe steuern alle Text-zu-Sprache-Ansagen. "Tonlautstärke" steuert die Start- und Endsignale des Rennens.

Anzeigetöne sind sehr kurze Töne, die Rückmeldung über die Funktionsweise des Timers geben und am nützlichsten sind, wenn Sie versuchen, ihn abzustimmen. Jeder Knoten ist mit einer eindeutigen Tonhöhe gekennzeichnet. "Crossing Entered" piept einmal, wenn ein Pass beginnt, und "Crossing Exited" piept zweimal schnell, wenn ein Pass abgeschlossen ist. Die Taste "Manuelle Runde" piept einmal, wenn mit der Taste "Manuell" ein simulierter Durchgang erzwungen wird.

#### Rennformat

Rennformate definieren, wie ein Rennen durchgeführt wird. Wähle ein aktives Rennformat. Einstellungen, die Sie hier anpassen, werden im aktuell aktiven Format gespeichert.

Der Renntimer kann nach oben oder unten zählen, wie im Renn-Timer-Modus ausgewählt. Verwenden Sie "No Time Limit" für einen "First to X Laps" -Stil mit einem Timer, der von Null aufwärts zählt. Verwenden Sie "Feste Zeit" für einen Timer, der nach dem Start des Rennens auf Null herunterzählt. Die Zeitdauer wird im Modus "Feste Zeit" verwendet, um die Länge des Rennens zu bestimmen.

Jedes Rennen beginnt mit einer Inszenierungssequenz. Race Staging kann mit einer festen oder variablen Anzahl von Staging-Sekunden und mit oder ohne Staging-Töne durchgeführt werden. Stellen Sie die _Minimum Start Delay_ und _Maximum Start Delay_ auf die Werte (in Sekunden) ein, die für die Rennstrecke gewünscht werden. Wenn diese Werte unterschiedlich sind, wählt der Timer einen zufälligen Wert für die Staging-Zeit. Zufällige Staging-Zeiten sind nützlich, um Fehlstarts zu verhindern. Der Timer zeigt während der Bereitstellung "Bereit" an und verdeckt die Startzeit des Rennens. Stellen Sie für eine feste Staging-Zeit "Minimum" und "Maximum" auf den gleichen Wert ein. Der Staging-Timer zeigt offen die Anzahl der Sekunden an, bis das Rennen beginnt.

_Eine kleine Zeit wird benötigt, um sicherzustellen, dass der Timer mit der gesamten Hardware synchronisiert wurde, sodass selbst bei einer Staging-Zeit von Null eine kurze Staging-Zeitspanne vorhanden ist._

Während der Staging-Sequenz kann eine Anzahl von Tönen erzeugt werden, wie durch _Staging-Töne_ festgelegt. Bei "Jede Sekunde" gibt der Timer während der Inszenierung kontinuierlich einen Ton aus. Mit "Eins" gibt der Timer sofort zu Beginn der Inszenierung einen Ton aus. Bei "Keine" wird keine akustische Warnung ausgegeben. Unabhängig von der Einstellung _Staging Tones_ wird der Ton "Race Start" immer noch abgespielt, wenn das Staging abgeschlossen ist und das Rennen beginnt.

_Win Condition_ bestimmt, wie der Timer den Gewinner des Rennens anruft, welche Informationen im OSD und in der Streaming-Anzeige angezeigt werden und welche Sortiermethode für Bestenlisten verwendet wird. Die Sortierung der Bestenlisten wirkt sich auf die Ergebnisseite und den Wärmeerzeuger aus.

* __Die meisten Runden in der schnellsten Zeit__: Die Piloten werden anhand der Anzahl der absolvierten Runden und der Dauer ihrer Runden beurteilt. Wenn es ein Unentschieden für die Anzahl der absolvierten Runden gibt, wird der Pilot, der diese Runden in kürzerer Zeit absolviert hat, höher eingestuft.
* __Nur die meisten Runden__: Wird nur nach der Anzahl der abgeschlossenen Runden gewertet. Piloten mit der gleichen Rundenzahl sind gebunden. Verwenden Sie den Modus "Feste Zeit" für einen Rennstil, bevor das Timing zuverlässig war, oder den Modus "Kein Zeitlimit", um die größte Distanz anstelle der kürzesten Zeit zu beurteilen.
* __Die meisten Runden nur mit Überstunden__: Ähnlich wie _Most Runden in der schnellsten Zeit_, jedoch mit einer Komponente "Plötzlicher Tod". Wenn der Timer abläuft (oder das Rennen vorzeitig abgebrochen wird), wenn ein Pilot mehr Runden als alle anderen hat, ist dieser Pilot der Gewinner. Wenn nach Ablauf des Timers ein Gleichstand für die Rundenanzahl besteht, ist der erste der gebundenen Piloten auf der ganzen Linie der Gewinner.
* __Erste bis X Runden__: Das Rennen wird fortgesetzt, bis ein Pilot die gewünschte Rundenzahl erreicht hat. In diesem Modus wird der Parameter _Number of Laps to Win_ verwendet. Wird normalerweise im Rennmodus _No Time Limit_ verwendet.
* __Schnellste Runde__: Ignoriert den Rennfortschritt und berücksichtigt nur die schnellste Einzelrunde jedes Piloten.
* __Schnellste 3 aufeinanderfolgende Runden__: Berücksichtigt alle Runden, die ein Pilot absolviert hat, und verwendet die drei aufeinander folgenden Runden mit der schnellsten kombinierten Zeit.
* __None__: Erklärt unter keinen Umständen einen Gewinner. Vorläufe, die aus einer Klasse mit dieser Bedingung generiert wurden, werden zufällig zugewiesen.

_Team Racing Mode_ aktiviert die alternative Wertung für zusätzliche Rennformate. Die Gewinnbedingungen im Teamrennmodus unterscheiden sich etwas:

* __Die meisten Runden in der schnellsten Zeit__: Die Teams werden anhand der Gesamtzahl der Runden aller Mitglieder und der Dauer dieser Runden beurteilt.
* __Nur die meisten Runden__: Die Teams werden anhand der Gesamtzahl der kombinierten Runden aller Mitglieder beurteilt.
* __Die meisten Runden nur mit Überstunden__: Die Teams werden anhand der Gesamtzahl der kombinierten Runden aller Mitglieder beurteilt. Wenn nach Ablauf der Zeit ein Gleichstand besteht, gewinnt das erste Team (von dem Unentschieden), das eine Runde hinzugefügt hat, den Sieger.
* __Erste bis X Runden__: Das erste Team, das die gewünschte Anzahl kombinierter Runden erreicht hat, ist der Gewinner.
* __Schnellste Runde__: Nachdem alle Teammitglieder eine Runde beigesteuert haben, werden die Teams anhand des Durchschnitts der schnellsten Rundenzeit der Piloten beurteilt.
* __Schnellste 3 aufeinanderfolgende Runden__: Nachdem alle Teammitglieder 3 Runden beigesteuert haben, werden die Teams anhand des Durchschnitts der schnellsten "drei aufeinander folgenden Runden" der Piloten beurteilt.

Mit _Fastest Lap_ und _Fastest 3 Consecutive Laps_ können Teams mit unterschiedlich vielen Piloten fair miteinander konkurrieren.

_Minimale Rundenzeit_ markiert oder verwirft Pässe, bei denen Runden registriert worden wären, die kürzer als die angegebene Dauer sind. Verwenden Sie das Verhalten "Verwerfen" mit Vorsicht, da dadurch möglicherweise gültige Daten entfernt werden. _Minimum Lap Time_ wird nicht im Rennformat gespeichert.

#### LED-Effekte

Wählen Sie für jedes Timer-Ereignis einen visuellen Effekt. Der Timer zeigt diesen Effekt an, wenn das Ereignis eintritt, und überschreibt sofort alle vorhandenen Anzeigen oder Effekte. Einige visuelle Effekte sind nur für bestimmte Timer-Ereignisse verfügbar. Einige visuelle Effekte werden durch das Ereignis verändert, insbesondere die Farbe der Ein- und Ausgänge der Gate-Kreuzung. Die meisten Effekte können über das LED-Bedienfeld in der Vorschau angezeigt werden.

Einige LED-Effekte können sich kurz verzögern, wenn der Timer mit zeitkritischen Aufgaben beschäftigt ist. (Andere wie der Start des Rennens werden nie verzögert.) Aufgrund dieses Effekts und möglicherweise gleichzeitiger Überfahrten sollte "Ausschalten" normalerweise für Torausgänge vermieden werden. Verwenden Sie stattdessen _"No Change"_ am Gate-Eingang und den gewünschten Effekt beim Gate-Ausgang.

_Dieser Abschnitt wird nicht angezeigt, wenn für Ihren Timer keine LEDs konfiguriert sind. Ein Hinweis wird im Startprotokoll angezeigt._

#### LED-Steuerung

Dieser Abschnitt überschreibt die aktuelle LED-Anzeige. Wählen Sie diese Option, um die Anzeige vorübergehend auszuschalten, einige vorkonfigurierte Farben anzuzeigen, benutzerdefinierte Farben anzuzeigen oder einen definierten Effekt anzuzeigen. Sie können auch den Schieberegler verwenden, um die Helligkeit Ihres Panels anzupassen. Die ideale Einstellung für FPV-Kameras ist, wenn das beleuchtete Feld der Helligkeit eines weißen Objekts entspricht. Dadurch liegt die Panel-Ausgabe innerhalb des Dynamikbereichs, den die Kamera erfassen kann. Die Verwendung einer niedrigen Helligkeitseinstellung verzerrt jedoch die Farbwiedergabe und die Glätte der Farbübergänge.

_Dieser Abschnitt wird nicht angezeigt, wenn für Ihren Timer keine LEDs konfiguriert sind. Ein Hinweis wird im Startprotokoll angezeigt._

#### Datenbank

Wählen Sie, ob Sie die aktuelle Datenbank sichern (in einer Datei auf dem Pi speichern und zum Herunterladen auffordern) oder Daten löschen möchten. Sie können Rennen, Klassen, Vorläufe und Piloten beenden.

#### System

Wählen Sie die Sprache der Benutzeroberfläche aus und ändern Sie Parameter, die sich auf das Erscheinungsbild des Timers auswirken, z. B. Name und Farbschema. Sie können den Server auch von hier aus herunterfahren.

### Lauf

Auf dieser Seite können Sie den Timer steuern und Rennen starten.

Wählen Sie die Hitze für das Rennen, das als nächstes ausgeführt werden soll.

Starten Sie das Rennen, wenn Sie bereit sind. (Hotkey: <kbd>z</kbd>). Der Timer führt eine schnelle Kommunikation mit dem Server durch, um die Client / Server-Antwortzeit zu kompensieren, und beginnt dann mit dem durch das aktuelle Race-Format definierten Staging-Verfahren.

Die Tuning-Parameter können hier über die Taste eingestellt werden.Eine ausführliche Beschreibung und Tuning-Anleitung finden Sie hier [doc/Tuning Parameters.md](de-Tuning%20Parameters.md).

Während des Rennens steht neben jeder gezählten Runde ein "×". Dadurch wird dieser Rundenpass verworfen, sodass seine Zeit auf die nächste Runde verschoben wird. Verwenden Sie diese Option, um fehlerhafte zusätzliche Pässe zu entfernen oder Piloten zu bereinigen, die nach Beendigung des Rennens in der Nähe des Starttors fliegen.

Durch Drücken der Taste "+ Runde" wird manuell ein Rundenpass für diesen Knoten ausgelöst.

Wenn ein Rennen beendet ist, verwenden Sie die Schaltfläche "Rennen stoppen" (Hotkey: <kbd>x</kbd>), um das Zählen von Runden abzubrechen. Sie müssen dies auch dann tun, wenn der Timer in einem "Countdown" -Format Null erreicht. Ein beliebtes Rennformat ermöglicht es den Piloten, die Runde zu beenden, auf der sie sich befinden, wenn die Zeit abgelaufen ist. Um optimale Ergebnisse zu erzielen, löschen Sie das Timing-Gate und lassen Sie alle gültigen Überfahrten enden, bevor Sie das Rennen beenden.

Sobald ein Rennen beendet ist, müssen Sie "Runden speichern" oder "Runden verwerfen" wählen, bevor Sie ein anderes Rennen starten. "Runden speichern" (Hotkey: <kbd>c</kbd>) speichert die Rennergebnisse in der Datenbank und zeigt sie auf der Seite "Ergebnisse" an. "Runden verwerfen" (Hotkey: <kbd>v</kbd>) verwirft die Rennergebnisse. Durch das Speichern von Runden wird die Auswahl des Laufs automatisch auf den nächsten Lauf mit derselben Klasse wie beim gespeicherten Rennen vorgerückt.

Das Race Management-Bedienfeld bietet schnellen Zugriff zum Ändern des aktuellen Rennformats, Profils, der minimalen Rundenzeit oder des Team-Rennmodus. _Audio Control_ und _LED Control_ entsprechen der Seite Einstellungen. Der Verlaufsexport gibt eine CSV-Datei aus, die von den aufgezeichneten RSSI-Werten des zuletzt abgeschlossenen Rennens heruntergeladen werden soll. "Zeit bis zum Start des Rennens" plant ein Rennen, das zu einem späteren Zeitpunkt durchgeführt werden soll. Die Betreiber können dies verwenden, um ein festes Limit für die Zeit festzulegen, die Piloten zur Vorbereitung benötigen, oder um den Timer zu starten und dann selbst am Rennen teilzunehmen.

### Marshal

Passen Sie die Ergebnisse gespeicherter Rennen an.

Wählen Sie die Runde, die Hitze und den Piloten aus, um sie anzupassen. Ein- und Ausstiegspunkte werden automatisch aus den gespeicherten Renndaten geladen. Passen Sie die Ein- und Ausstiegspunkte an, um das Rennen nachträglich neu zu kalibrieren. "Vom Knoten laden", um aktuelle Live-Kalibrierungsdaten über die aktiven Werte zu kopieren. "Auf Knoten speichern", um die aktiven Werte über die aktuellen Live-Werte zu kopieren. "Rennen neu berechnen", um die aktiven Ein- / Ausstiegswerte als Kalibrierungspunkte für eine "Wiederholung" des Rennens zu verwenden. Dadurch werden aktuelle Runden gelöscht und durch die neu berechneten Informationen ersetzt. Manuell eingegebene Runden bleiben erhalten.

Fügen Sie Runden hinzu, indem Sie die Überfahrtzeit in Sekunden ab Rennbeginn eingeben und dann auf die Schaltfläche "Runde hinzufügen" klicken.

Löschen Sie Runden mit der Taste "×" in der unerwünschten Runde. Gelöschte Runden werden aus den Berechnungen entfernt, bleiben jedoch zur späteren Bezugnahme in den Daten vorhanden. "Runden verwerfen", um die Daten dauerhaft aus der Datenbank zu entfernen.

Sie können auf das Diagramm klicken / es berühren, um Ein- / Ausstiegspunkte festzulegen, die Neuberechnung zu aktivieren und bestimmte Runden hervorzuheben. Durch Klicken auf Runden in der Liste wird auch eine Markierung in der Grafik hinzugefügt. Drücken Sie <kbd>delete</kbd> oder <kbd>x</kbd>, um eine markierte Runde zu löschen. Aktive Runden werden grün angezeigt und gelöschte Runden werden rot. Die Breite der Rundenanzeige zeigt die Ein- / Ausstiegspunkte an, und die gelbe Markierung zeichnet eine Linie zur genauen Rundenzeit in diesem Fenster.

"Änderungen übernehmen", wenn Sie mit dem Anpassen der Renndaten fertig sind, um sie in der Datenbank zu speichern und die Rennergebnisse zu aktualisieren.

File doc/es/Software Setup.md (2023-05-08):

#Instrucciones de configuración de software

El componente de software central del sistema RotorHazard es su servidor, escrito en Python, que opera sus funciones y sirve páginas web para los navegadores. En una configuración estándar, el servidor se ejecuta en un RaspberryPi. (También es posible ejecutar RotorHazard en otros tipos de hardware; consulte el[Other Operating Systems](#otheros) section below.)

##Instalar sistema (Raspberry Pi)
Nota: Muchos de los comandos de configuración a continuación requieren que Raspberry Pi tenga acceso a Internet.
Comience instalando Raspbian, siguiendo las instrucciones oficiales aquí: https://www.raspberrypi.org/downloads/raspbian/. Puede usar Desktop o Lite.

Configure las opciones de interfaz en la Raspberry Pi.
Abra una ventana de Terminal e ingrese el siguiente comando:
```
sudo raspi-config
```
Seleccione Opciones de Interfaz y habilite: SSH, SPI y I2C.

Actualice el sistema (esto puede tardar unos minutos):
```
sudo apt-get update && sudo apt-get upgrade
```

Instale Python y los drivers de Python para GPIO.
```
sudo apt-get install python-dev python-rpi.gpio libffi-dev python-smbus build-essential python-pip git scons swig
```

Instale la interfaz de la función en Python
```
sudo pip install cffi
```

Actualice el baudrate de puerto i2C
```
sudo nano /boot/config.txt
```
Añada las siguientes líneas al final del archivo config.txt:
```
dtparam=i2c_baudrate=75000
core_freq=250
```
Guarde y salga del archivo con Ctrl-X

Instale el código RotorHazard en '/ home / pi /' en la Raspberry Pi de la siguiente manera: Vaya a [Latest Release page](https://github.com/RotorHazard/RotorHazard/releases/latest) para el proyecto y tenga en cuenta el código de versión. En los siguientes comandos, reemplace las dos apariciones de "1.2.3" con el código de la versión actual e ingrese los comandos:
```
cd ~
wget https://codeload.github.com/RotorHazard/RotorHazard/zip/v1.2.3 -O temp.zip
unzip temp.zip
mv RotorHazard-1.2.3 RotorHazard
rm temp.zip
```

Instale las dependencias del servidor RotorHazard (sea paciente, este comando puede tardar unos minutos):
```
cd ~/RotorHazard/src/server
sudo pip install -r requirements.txt
```

Actualizar permisos en la carpeta de trabajo:
```
cd ~/RotorHazard/src
sudo chmod 777 server
```

* Nota: Si RotorHazard ya está instalado, consulte el [Updating an existing installation](#update) sección abajo.*

## Instalar el Código en los Nodo Receptores (Arduinos)
Requiere Arduino 1.8 o superior. Descárguelo de https://www.arduino.cc/en/Main/Software

* El código de nodo y la versión del servidor deben coincidir. Utilice el código 'nodo' incluido con el código del servidor que descargó anteriormente; no descargue un archivo diferente directamente desde GitHub. *

El código de nodo se puede editar y construir utilizando el[Eclipse IDE](https://www.eclipse.org/eclipseide/) y el "[Eclipse C++ IDE for Arduino](https://marketplace.eclipse.org/content/eclipse-c-ide-arduino)"plugin (o la forma tradicional usando el IDE de Arduino). En Eclipse, el proyecto de código de nodo se puede cargar a través de "Archivo | Abrir proyectos desde el sistema de archivos ..."

Edite el archivo 'src / node / config.h' y configure el valor '#define NODE_NUMBER' para cada nodo antes de cargarlo. Para el primer nodo, configure NODE_NUMBER en 1, para el segundo configúrelo en 2, etc.

```
// Node Setup -- Set node number here (1 - 8)
#define NODE_NUMBER 1
```
También se puede configurar de manera automática los nodos mediante la conexión a tierra de estos pines de los Arduinos. Establezca NODE_NUMBER en 0, luego empalme estos pines a tierra (GND):

nodo #1: GND a pin D5<br/>
nodo #2: GND a pin D6<br/>
nodo #3: GND a pin D7<br/>
nodo #4: GND a pin D8<br/>
nodo #5: GND a pin D5 y pin D4<br/>
nodo #6: GND a pin D6 y pin D4<br/>
nodo #7: GND a pin D7 y pin D4<br/>
nodo #8: GND a pin D8 y pin D4<br/>

## Instalar Componentes opcionales
### Soporte WS2812b LED
Los controles de los LED ws2812b se proporcionan en el siguiente proyecto:
https://github.com/jgarff/rpi_ws281x

Clone el repositorio en la Pi e inicie Scons:
```
cd ~
sudo git clone https://github.com/jgarff/rpi_ws281x.git
cd rpi_ws281x
sudo scons
```

Instale la bilblioteca Python:
```
cd python
sudo python setup.py install
```

### Sensor de Voltage/Current INA219
La interfaz ina219 se proporciona en el siguiente proyecto:
https://github.com/chrisb2/pi_ina219

Clone el repositorio en la Pi:
```
cd ~
sudo git clone https://github.com/chrisb2/pi_ina219.git
cd pi_ina219
```
Instale la biblioteca Python:
```
sudo python setup.py install
```

### Sensor de Temperatura BME280
La interfaz bme280 se proporciona en el siguiente proyecto:
https://github.com/rm-hull/bme280

Clone el repositorio en la Pi:
```
cd ~
sudo git clone https://github.com/rm-hull/bme280.git
cd bme280
```
Instale la biblioteca Python:
```
sudo python setup.py install
```

### Soporte Java
Java permite el cálculo de las puntuaciones de IMD. Si comenzó con RASPBIAN WITH DESKTOP, este paso no debería ser necesario ya que Java está instalado de manera predeterminada. De otra manera:
```
sudo apt install default-jdk-headless
```

## Preparar el Sistema
### Reiniciar el Sistema
Después de realizar los pasos de configuración anteriores, el sistema debe reiniciarse ingresando lo siguiente:
```
sudo reboot
```

### Arrancando el Sistema

Las siguientes instrucciones iniciarán el servidor web en la raspberryPi, permitiendo el control total y la configuración del sistema para lanzar carreras y guardar los tiempos de vuelta.

#### Arranque Manual
Abra un terminal y escriba lo siguiente:
```
cd ~/RotorHazard/src/server
python server.py
```
El servidor se puede parar pulsando Ctrl+c

#### Arranque de inicio
Cree un servicio
```
sudo nano /lib/systemd/system/rotorhazard.service
```
con el siguiente contenido:
```
[Unit]
Description=RotorHazard Server
After=multi-user.target

[Service]
WorkingDirectory=/home/pi/RotorHazard/src/server
ExecStart=/usr/bin/python server.py

[Install]
WantedBy=multi-user.target
```
Guarde y salga (CTRL-X, Y, ENTER).

Actualice los permisos.
```
sudo chmod 644 /lib/systemd/system/rotorhazard.service
```

Inicio con los comandos de arranque.
```
sudo systemctl daemon-reload
sudo systemctl enable rotorhazard.service
sudo reboot
```

### Apagando el Sistema
El apagado del sistema siempre debe realizarse antes de desconectar la alimentación, ya sea haciendo clic en el botón 'Apagar' en la página 'Configuración' o ingresando lo siguiente en un terminal:
```
sudo shutdown now
```

### Actualizar una instalación existente

Antes de actualizar, se debe detener cualquier servidor RotorHazard que se esté ejecutando actualmente. Si se instala como un servicio, se puede detener con un comando como: `sudo systemctl stop rotorhazard`

Para actualizar una instalación existente de RotorHazard: vaya a [Latest Release page](https://github.com/RotorHazard/RotorHazard/releases/latest) para el proyecto y tenga en cuenta el código de versión. En los siguientes comandos, reemplace las dos apariciones de "1.2.3" con el código de la versión actual e ingrese los comandos:
```
cd ~
wget https://codeload.github.com/RotorHazard/RotorHazard/zip/1.2.3 -O temp.zip
unzip temp.zip
mv RotorHazard RotorHazard.old
mv RotorHazard-1.2.3 RotorHazard
rm temp.zip
cp RotorHazard.old/src/server/config.json RotorHazard/src/server/
cp RotorHazard.old/src/server/database.db RotorHazard/src/server/
```
La instalación anterior termina en el directorio 'RotorHazard.old', que se puede eliminar o mover.

Las dependencias del servidor RotorHazard también deben actualizarse (tenga paciencia, este comando puede tardar unos minutos):
```
cd ~/RotorHazard/src/server
sudo pip install --upgrade --no-cache-dir -r requirements.txt
```
<br/>

-----------------------------

### Otros sistemas operativos

El servidor RotorHazard puede ejecutarse en cualquier computadora con un sistema operativo que admita Python. En estas configuraciones alternativas, uno o más nodos de hardware se pueden conectar a través de USB; consulte [doc/USB Nodes.md](USB%20Nodes.md) para más información. El servidor también puede ejecutarse utilizando nodos simulados.

To install the RotorHazard server on these systems:

1. Si el ordenador aún no tiene Python instalado, descargue e instale Python versión 2.7 de https://www.python.org/downloads. Para verificar si Python está instalado, abra un símbolo del sistema e ingrese ```python --version```

1. Desde el RotorHazard [Releases page on github](https://github.com/RotorHazard/RotorHazard/releases), descargar el archivo "Source code (zip)".

1. Descomprima el archivo descargado en un directorio (también conocido como carpeta) en el ordenador.

1. Abra un símbolo del sistema y navegue hasta el directorio `` src / server`` en los archivos RotorHazard (usando el comando 'cd').

1. Instale las dependencias del servidor RotorHazard utilizando el archivo 'require.txt'. En un sistema Windows, el comando a usar probablemente será: ```python -m pip install -r requirements.txt```<br/>Tenga en cuenta que este comando puede requerir acceso de administrador al ordenador, y el comando puede tardar unos minutos en finalizar)

Para ejecutar el servidor RotorHazard en estos sistemas:

1. Abra un símbolo del sistema y navegue hasta el directorio ```src/server``` en los archivos RotorHazard (si aún no está allí).

1. Teclee: ```python server.py```

1. Si el servidor se inicia correctamente, debería ver varios mensajes de registro, incluido uno como este:
    ```
    Running http server at port 5000
    ```

1. El servidor se puede detener presionando Ctrl+C

Si los nodos de hardware están conectados a través de USB, deberán configurarse en la sección "SERIAL_PORTS" en el archivo de configuración "src / server / config.json" (consulte [doc/USB Nodes.md](USB%20Nodes.md) para detalles).

Si no hay configurados nodos de hardware, el servidor funcionará utilizando nodos simulados (simulados). En este modo, se puede explorar y probar la interfaz web-GUI.

Para ver la interfaz web-GUI, abra un navegador web e ingrese en la barra de direcciones: ```localhost:5000``` (Si el valor HTTP_PORT en la configuración ha cambiado, use ese valor en lugar de 5000). Si el servidor se está ejecutando, debería aparecer la página principal de RotorHazard. Tenga en cuenta que las páginas reservadas para el director de carrera (Administrador / Configuración) están protegidas con contraseña con el nombre de usuario y la contraseña especificados en la configuración.

<br/>

-----------------------------

Vea también:<br/>
[doc/Hardware Setup.md](Hardware%20Setup.md)<br/>
[doc/USB Nodes.md](USB%20Nodes.md)<br/>
[doc/User Guide.md](User%20Guide.md)

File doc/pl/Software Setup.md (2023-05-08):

# Instrukcje Konfiguracji Oprogramowania

Głównym komponentem oprogramowania systemu RotorHazard jest jego serwer, napisany w języku python, który operuje jego funkcjami i służy jako serwer web dla przeglądarki. W standardowym ustawieniu serwer jest włączony na Raspberry Pi. Możliwe jest włączenie RotorHazard na innym typie urządzenia – zobacz poniżej sekcję [Inne Systemy Operacyjne](#otheros).
## Zainstaluj System – (Raspberry Pi)
Uwaga: Wiele spośród wymienionych niżej komend wymaga połączenia z Internetem.

Zacznij od instalacji systemu Raspbian. Postępuj zgodnie z oficjalnymi instrukcjami na stronie:
https://www.raspberrypi.org/downloads/raspbian/. Możesz użyć wersji Desktop albo Lite.

Skonfiguruj interfejs na Raspberry Pi. Otwórz okno terminala i wpisz następujące komendy:
```
sudo raspi-config
```
Wybierz Interfacing Options i włącz: SSH, SPI, and I2C.

Wykonaj aktualizację systemu – może zająć kilka minut:
```
sudo apt-get update && sudo apt-get upgrade
```
Zainstaluj python i sterowniki python dla GPIO:
```
sudo apt-get install python-dev python-rpi.gpio libffi-dev python-smbus build-essential python-pip git scons swig
```
Zainstaluj interfejs funkcji dla python:
```
sudo pip install cffi
```
Zaktualizuj przepływność magistrali I2C:
```
sudo nano /boot/config.txt
```
Dodaj następujące linie na końcu pliku:
```
dtparam=i2c_baudrate=75000
core_freq=250
```
Zapisz i zamknij naciskając Ctrl+X.

Zainstaluj RotorHazard w '/home/pi/' na Raspberry Pi następujący sposób:
Idź do strony [Latest Release page](https://github.com/RotorHazard/RotorHazard/releases/latest)

„Ostatnie wydania” i zobacz jaka jest aktualna wersja kodu. W komendach poniżej zastąp znaki "1.2.3" aktualną wersję kodu i wpisz następujące komendy:
```
cd ~
wget https://codeload.github.com/RotorHazard/RotorHazard/zip/v1.2.3 -O temp.zip
unzip temp.zip
mv RotorHazard-1.2.3 RotorHazard
rm temp.zip
```
Zainstaluj tak zwane „zależności” serwera RotorHazard - bądź cierpliwy może zająć to kilka minut:
```
cd ~/RotorHazard/src/server
sudo pip install -r requirements.txt
```
Zmień ustawienia dostępu dla folderu:
```
cd ~/RotorHazard/src
sudo chmod 777 server
```
Uwaga: jeśli RotorHazard jest już zainstalowany, zobacz w sekcji poniżej[uaktualnianie obecnej instalacji](#update).

## Zainstaluj kod dla odnóg Arduino
Wymagane jest Arduino w wersji minimum 1.8. Ściągnij z:
https://www.arduino.cc/en/Main/Software

*Wersja oprogramowania dla odnóg oraz serwera muszą do siebie pasować. Użyj kodu przygotowanego dla odnóg z tego samego folderu, z którego instalujesz serwer. Nie ściągaj innych plików bezpośrednio z GitHub.*

Kod dla odnóg może być edytowany i przygotowany używając [Eclipse IDE](https://www.eclipse.org/eclipseide/) i "[Eclipse C++ IDE dla Arduino](https://marketplace.eclipse.org/content/eclipse-c-ide-arduino)" (albo “po-staremu” używając Arduino IDE). W Eclipse projekt zawierający kod dla odnóg może być otwarty poprzez „Plik”, „Otwórz projekt z pliku systemowego…”

Edytuj plik 'src/node/config.h' i skonfiguruj wartość '#define NODE_NUMBER' dla każdej odnogi przed uaktualnieniem. Dla pierwszej odnogi ustaw NODE_NUMBER jako 1, dla drugiej ustaw jako 2, itd.
```
// Node Setup -- Set node number here (1 - 8)
#define NODE_NUMBER 1
```
Automatyczne numerowanie sprzętowe, również jest możliwe. Ustaw NODE_NUMBER jako 0, następnie połącz następujące piny z masą:

node #1: pin D5 podłączony do masy<br/>
node #2: pin D6 podłączony do masy<br/>
node #3: pin D7 podłączony do masy<br/>
node #4: pin D8 podłączony do masy<br/>
node #5: pin D5 i pin D4 podłączone do masy<br/>
node #6: pin D6 i pin D4 podłączone do masy<br/>
node #7: pin D7 i pin D4 podłączone do masy<br/>
node #8: pin D8 i pin D4 podłączone do masy

## Zainstaluj Opcjonalne Składniki
### Wsparcie dla LEDów WS2812b
Kontrola nad WS2812b jest dostarczona przez następujący projekt:
https://github.com/jgarff/rpi_ws281x

Sklonuj repozytorium na Pi i zainicjuj Scons:
```
cd ~
sudo git clone https://github.com/jgarff/rpi_ws281x.git
cd rpi_ws281x
sudo scons
```

Zainstaluj bibliotekę Python:
```
cd python
sudo python setup.py install
```

### Wsparcie dla miernika Napięcia/Natężenia INA219
Interfejs INA219 jest dostarczony przez następujący projekt:
https://github.com/chrisb2/pi_ina219

Sklonuj repozytorium na Pi:
```
cd ~
sudo git clone https://github.com/chrisb2/pi_ina219.git
cd pi_ina219
```
Zainstaluj bibliotekę Python:
```
sudo python setup.py install
```

### Wsparcie dla czujnika temperatury BME280
Interfejs BME280 jest dostarczony przez następujący projekt: https://github.com/rm-hull/bme280

Sklonuj repozytorium na Pi:
```
cd ~
sudo git clone https://github.com/rm-hull/bme280.git
cd bme280
```
Zainstaluj bibliotekę Python:
```
sudo python setup.py install
```

### Java Support
Java umożliwia kalkulację oceny zniekształceń intermodulacyjnych „IMD score”. Jeśli zainstalowałeś w kroku pierrwszym “RASPBIAN WITH DESKTOP”, ten krok nie powinien być konieczny. W innym wypadku:
```
sudo apt install default-jdk-headless
```

## Przygotuj System
### Zrestartuj System
Po tym jak powyższe kroki zostaną przeprowadzone system powinien być zrestartowany poprzez następujące komendy:
```
sudo reboot
```

### Uruchom System
Następujące instrukcje włączą serwer web na Raspberry Pi, umożliwiając pełną kontrolę oraz konfigurację systemu, aby móc przeprowadzać wyścigi i zapisywać czasy okrążeń.

#### Manualny Start
Otwórz okno terminal i wpisz:
```
cd ~/RotorHazard/src/server
python server.py
```
Serwer może być zatrzymany poprzez wciśnięcie Ctrl+C

#### Uruchamianie podczas rozruchu
Stwórz usługę
```
sudo nano /lib/systemd/system/rotorhazard.service
```
Z następującą zawartością:
```
[Unit]
Description=RotorHazard Server
After=multi-user.target

[Service]
WorkingDirectory=/home/pi/RotorHazard/src/server
ExecStart=/usr/bin/python server.py

[Install]
WantedBy=multi-user.target
```
Zapisz i wyjdź (CTRL+X, Y, ENTER).

Zaktualizuj ustawienia dostępu.
```
sudo chmod 644 /lib/systemd/system/rotorhazard.service
```

Komendy uruchamiania podczas rozruchu:
```
sudo systemctl daemon-reload
sudo systemctl enable rotorhazard.service
sudo reboot
```

### Wyłączanie Systemu
System powinien zawsze być prawidłowo wyłączony przed odłączeniem zasilania – poprzez wciśnięcie przycisku w Ustawieniach lub poprzez wpisanie następującej komendy:
```
sudo shutdown now
```

### Uaktualnianie obecnej instalacji

Przed uaktualnieniem, wszystkie obecnie uruchomione serwery powinny być zatrzymane. Jeśli serwer jest zainstalowany jako usługa, może być zatrzymany przez wpisanie komendy: `sudo systemctl stop rotorhazard`

Aby uaktualnić obecną instalację RotorHazard: Idź do [Latest Release page](https://github.com/RotorHazard/RotorHazard/releases/latest) „Ostatnie wydania” i zobacz jaka jest aktualna wersja kodu. W komendach poniżej zastąp znaki "1.2.3" aktualną wersję kodu i wpisz następujące komendy:
```
cd ~
wget https://codeload.github.com/RotorHazard/RotorHazard/zip/1.2.3 -O temp.zip
unzip temp.zip
mv RotorHazard RotorHazard.old
mv RotorHazard-1.2.3 RotorHazard
rm temp.zip
cp RotorHazard.old/src/server/config.json RotorHazard/src/server/
cp RotorHazard.old/src/server/database.db RotorHazard/src/server/
```
Poprzednia instalacja znajdzie się w folderze 'RotorHazard.old', który może zostać usunięty lub przeniesiony.

„Zależności” RotorHazard również powinny być uaktualnione – bądź cierpliwy – może to zająć kilka minut:
```
cd ~/RotorHazard/src/server
sudo pip install --upgrade --no-cache-dir -r requirements.txt
```
<br/>

-----------------------------

### Pozostałe Systemy Operacyjne

Serwer RotorHazard może być uruchomiony na każdym komputerze obsługującym python. W tych alternatywnych konfiguracjach, jedna albo więcej odnóg może być podłączona przez USB – zobacz [doc/USB Nodes.md](USB%20Nodes.md) aby uzyskać więcej informacji. Serwer może również być włączony używając “wirtualnych” (sztucznych) odnóg.

Aby zainstalować serwer RotorHazard na tych systemach:

1. Jeśli komputer nie posiada zainstalowanego Python’a w wersji 2.7 zainstaluj go z https://www.python.org/downloads. Żeby sprawdzić czy Python jest zainstalowany, otwórz wiersz poleceń i wpisz ```python --version```

2. Z RotorHazard [Releases page on github](https://github.com/RotorHazard/RotorHazard/releases), ściągnij plik "Source code (zip)".

3. Rozpakuj ściągnięty plik w folderze, na komputerze.

4. Otwórz wiersz poleceń i nawiguj do pliku ```src/server``` w plikach RotorHazard (używając komend 'cd’).

5. Zainstaluj “zależności” serwera RotorHazard używając pliku 'requirements.txt'. Na systemie Windows komenda jakiej prawdopodobnie będziesz musiał użyć to: ```python -m pip install -r requirements.txt```<br/>
Zwróć uwagę, że ta komenda może wymagać uprawnień administratora i jej wykonanie może zająć kilka minut.

Aby uruchomić serwer RotorHazard na tych systemach:

1. Otwórz wiersz poleceń i nawiguj do pliku ```src/server``` w plikach RotorHazard (chyba, że już się tam znajdujesz).

2. Wpisz: ```python server.py```

3. Jeśli serwer uruchomił się prawidłowo, powinieneś zobaczyć wiersz log’ów, np:
    ```
    Running http server at port 5000
    ```

4. Serwer może być zatrzymany poprzez naciśnięcie Ctrl+C

Jeśli odnogi są podłączone poprzez USB, muszą zostać skonfigurowane w sekcji "SERIAL_PORTS" w pliku konfiguracyjnym "src/server/config.json" (zobacz [doc/USB Nodes.md](USB%20Nodes.md) aby uzyskać szczegółowe informacje).

Jeśli żadna odnoga sprzętowa nie jest skonfigurowana, serwer będzie operował używając symulowanych – sztucznych – odnóg. w tym trybie interfejs web może byś testowany i eksplorowany.

Aby obejrzeć interfejs web, otwórz przeglądarkę internetową i wpisz w pole adresu: ```localhost:5000``` (jeśli HTTP_PORT w konfiguracji został zmieniony, wpisz wybraną wartość zamiast 5000). Jeśli serwer uruchomiony, wtedy strona główna RotorHazard powinna się pojawić. Zwróć uwagę że strony przynależne do zarządzającego zawodami (Admin/Settings) są chronione hasłem z nazwą użytkownika i hasłem ustalonymi w pliku konfiguracyjnym.
<br/>

-----------------------------

Zobacz również:<br/>
[doc/Hardware Setup.md](Hardware%20Setup.md)<br/>
[doc/USB Nodes.md](USB%20Nodes.md)<br/>
[doc/User Guide.md](User%20Guide.md)

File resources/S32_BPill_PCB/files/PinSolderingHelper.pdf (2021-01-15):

Pin Soldering Helper

When solder single or even dual pin headers onto a PCB it can be difficult or frustrating to get them straight without burning yourself. Here is how to make a simple helper to make the process a lit bit easier.

First, start with a 3- or 4-pin high-profile socket and cut its pins off flush so that it can sit flat:

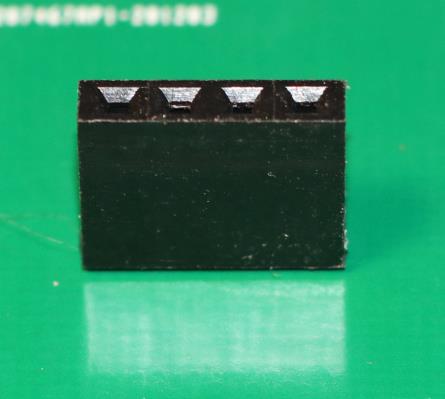
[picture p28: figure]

Then take two single pins and insert them into the socket. You can see from the photo that these were broken off of a longer header pin strip:

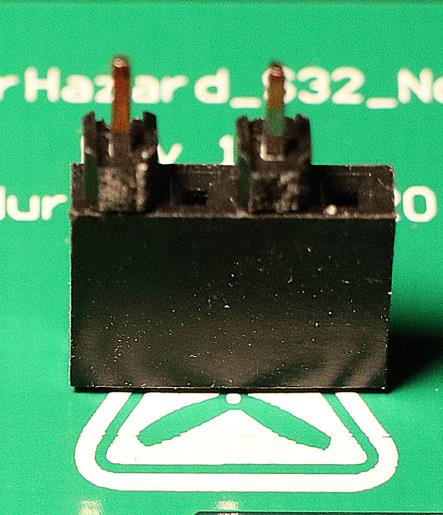
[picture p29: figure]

Then cut off the tails of the pins flush and push the pins down so they are completely below the plastic surround:

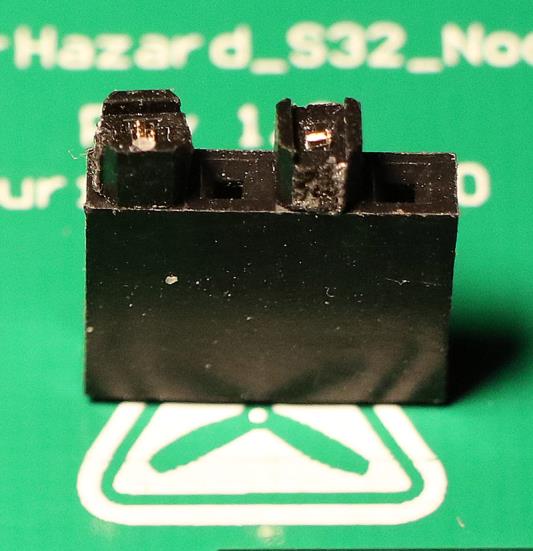
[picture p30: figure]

Insert the pin to be soldered between the other two pins and you now have a nice holder that will make it easier to hold the single pin for soldering without burning your fingers:

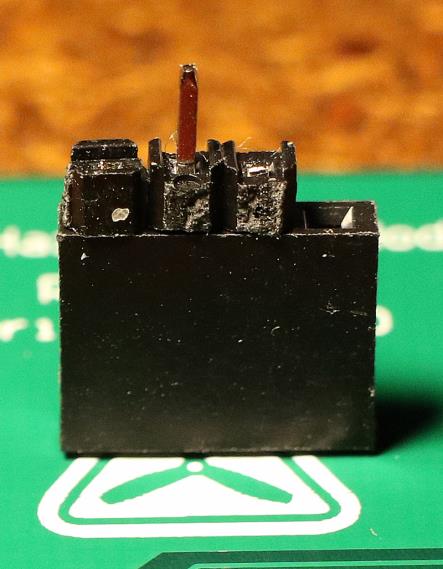
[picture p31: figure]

It will also make it easier to hold the pin vertical in the first place. This helper can also make it easier to hold 2-pin (or more) headers perpendicular to the PCB while soldering:

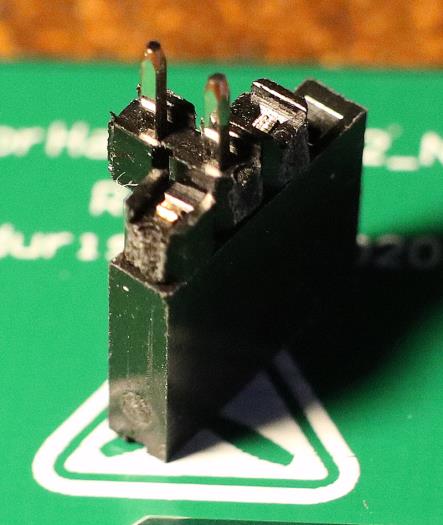
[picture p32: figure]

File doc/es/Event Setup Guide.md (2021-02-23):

# Gía de configuración de Evento

Los conceptos básicos de la configuración de un evento son la configuración de pilotos, series y nodos. También puede agregar detalles del evento y clases de carrera si lo desea.

## Borrar datos existentes (si fuese necesario)
Desde Configuración, abrir Base de datos. Usar entre las opciones disponibles para borrar los datos que sean obsoletos.

## Añadir Detalles al Evento (opcional)
Desde Configuración, abra el panel Evento. Actualice el nombre y la descripción del evento. Estos se mostrarán en la página de inicio cuando los usuarios visiten el RotorHazard por primera vez. Aquí puede informar a los pilotos qué pueden esperar del evento, como cuál será el formato o el horario.

## Añadir Pilotos
Desde Configuración, abra el panel Pilotos. Agregue una entrada para cada piloto que participe. El nombre del piloto se mostrará en la página del evento; Callsign (alias) se usará para mostrar los resultados de la carrera y las llamadas de voz. Prueba la pronunciación de la voz con el botón ">". Si lo desea, escriba una ortografía fonética para los nombres que no suenen igual. Esto nunca se mostrará, pero se usa para pronunciar el nombre.

## Crear Formatos de Carrera (opcional)
Desde Configuración, abrir Formato de Carreras. [Adjust the settings](User%20Guide.md#race-format) o crear nuevos formatos para que coincidan con el tipo de puesta en escena de inicio de su grupo, la condición de victoria, etc.
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

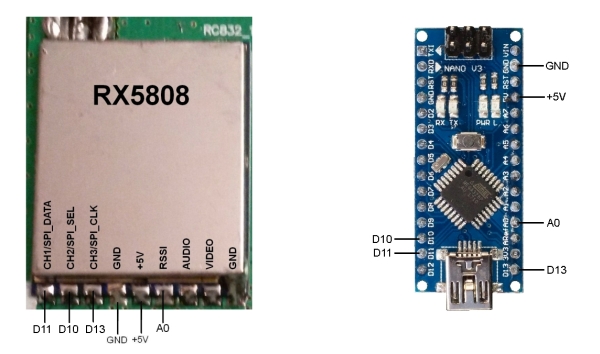
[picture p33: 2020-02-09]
doc/img/USB_node_wiring.jpg

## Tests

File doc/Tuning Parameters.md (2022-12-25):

# Calibration and Sensor Tuning Parameters

- [Introduction](#introduction)
- [Parameters](#parameters)
    - [EnterAt](#enterat)
    - [ExitAt](#exitat)
    - [Calibration Mode](#calibration-mode)
    - [Start of Race EnterAt/ExitAt Lowering](#start-of-race-enteratexitat-lowering)
- [Tuning](#tuning)
    - [Set the *EnterAt* value](#set-the-enterat-value)
    - [Set the *ExitAt* value](#set-the-exitat-value)
    - [Tuning Example](#tuning-example)
    - [Alternate Tuning Method](#alternate-tuning-method)
- [Notes](#notes)
- [Troubleshooting](#troubleshooting)
    - [Missing Laps (System usually *Clear*)](#missing-laps-system-usually-clear)
    - [Missing Laps (System usually *Crossing*)](#missing-laps-system-usually-crossing)
    - [Laps register on other parts of a course](#laps-register-on-other-parts-of-a-course)
    - [Many laps register at once](#many-laps-register-at-once)
    - [Laps take a long time to register](#laps-take-a-long-time-to-register)
    - [Node is never *crossing*](#node-is-never-crossing)
    - [Node is never *clear*](#node-is-never-clear)

## Introduction

_If you are having trouble calibrating your timer, be sure you have constructed and placed [RF shielding](Shielding%20and%20Course%20Position.md) correctly._

Each node keeps track of the signal strength (RSSI) on a selected frequency and uses this relative strength to determine whether a transmitter is near the timing gate. The RotorHazard timing system allows you to calibrate each node individually so that you can compensate for the behavior and hardware differences across your system and environment.

A node can be *Crossing* or *Clear*. If a node is *Clear*, the system believes a transmitter is not near the timing gate because the RSSI is low. If it is *Crossing*, the system believes a transmitter is passing by the timing gate because the RSSI is high. A lap pass will be recorded once the *Crossing* is finished and the system returns to *Clear*.

Tuning Graph<br />
_RSSI during a race appears similar to this graph with many visible peaks and valleys. As the transmitter nears the timing gate, the signal rises._

## Parameters
Two parameters that affect the *Crossing* status: *EnterAt* and *ExitAt*.

### EnterAt
The system will switch to *Crossing* when RSSI raises to or above this level. It is indicated by a red line.

### ExitAt
The system will switch to *Clear* once the RSSI value drops below this level. It is indicated by an orange line.

In between *EnterAt* and *ExitAt*, the system will remain *Crossing* or *Clear* depending on its previous state.

Sample RSSI Graph

### Calibration Mode

*Manual* calibration mode will always use the *EnterAt* and *ExitAt* values provided by the user.

*Adaptive* calibration mode uses the user-defined points unless there are saved races. When saved races exist, changing heats will initiate a search of previous race data for the best calibration values to use in the upcoming race. These values are copied and replace the current *EnterAt* and *ExitAt* values for all nodes. This mode improves calibration as more races are saved if the race director confirms the incoming lap counts or recalculates them through the *Marshal* page.

### Start of Race EnterAt/ExitAt Lowering

At the beginning of a race there can be many quads going through the start gate at the same time, and this can result in lower RSSI values being detected on some of the nodes (which could result in an initial gate pass being missed). To account for this, the following settings may be configured:

*Start of race EnterAt/ExitAt lowering amount (percent):* Sets the amount that the EnterAt and ExitAt values for all nodes will be reduced, as a percentage. For instance, if 30 (percent) is configured, the EnterAt value will be lowered to a value that is 30% closer to the ExitAt value. (So if EnterAt=90 and ExitAt=80, the EnterAt value will be lowered to 87.) The ExitAt value will be also be lowered by the same amount.

*Start of race EnterAt/ExitAt lowering duration (seconds):* Sets the maximum amount of time (in seconds) that the EnterAt and ExitAt values will be lowered. If a gate crossing for a node is detected as completed before this time then the EnterAt and ExitAt values for that node will be restored then.

Suggested values are 30 (percent) and 10 (seconds). If either of these settings are configured as zero then the EnterAt and ExitAt values will not be lowered.

Note that on the *Marshal* page these settings are taken into consideration, so if they are non-zero then the first lap pass on a node may be detected even though the peak RSSI appears to be lower than the EnterAt level displayed.

## Tuning
Before tuning, power up the timer and keep it running for a few minutes to allow the receiver modules to warm up. The RSSI values tend to increase by a few points as the timer heats up.

You can use the *Marshal* page to tune values visually. Collect data by running a race with a pilot on each channel, then save it. Open the *Marshal* page and view the race data, adjusting Enter and Exit points until the number of laps is correct. Save the Enter/Exit points to each node to use as calibration for future races.

### Set the *EnterAt* value
Tuning Graph

* Below the peak of all gate crossings
* Above any peak when the transmitter is not near the gate
* Higher than *ExitAt*

### Set the *ExitAt* value
Tuning Graph

* Below any valleys that occur during a gate crossing
* Above the lowest value seen during any lap
* Lower than *EnterAt*

ExitAt values set close to EnterAt allow the timer to announce and display laps quickly, but may not prevent multiple laps from being recorded during a single gate pass.

### Tuning Example
Tuning Graph<br />
_Two laps are recorded. The signal rises above *EnterAt* and then falls below *ExitAt* twice, once at each peak. Within these two crossing windows, the timer finds the strongest signal (after noise filtering) to use as the recorded lap time._

### Alternate Tuning Method

The *Capture* buttons may be used to store the current RSSI reading as the *EnterAt* or *ExitAt* value for each node. The values may also be entered and adjusted manually.

Power up a quad on the correct channel and bring it very close to the timer for a few seconds. This will allow the timer to capture the peak RSSI value for that node. This should be done for each node/channel that is being tuned. The peak value will be displayed.

#### EnterAt
A good starting point for *EnterAt* is to capture value with a quad about 1.5–3m (5–10 ft) away from the timer.

#### ExitAt
A good starting point for *ExitAt* is to capture the value with a quad about 6–9m (20–30 ft) away from the timer.

## Notes
* A low *ExitAt* value can still provide accurate timing, but the system will wait longer before announcing laps. A delay in announcing does not affect the accuracy of the timer.
* The *Minimum Lap Time* setting can be used to prevent extra passes, but might mask crossings that are triggered too early. It is strongly recommended to set the behavior to *Highlight* (rather than *Discard*) and review each incidence.
* If you experience timing issues during a race but the RSSI is responding to the pilot's transmitter, do not stop the race. Save the race after it completes and visit the *Marshal* page. RSSI history is saved and the race can be accurately recalculated with updated tuning values.

## Troubleshooting

### Missing Laps (Node usually *Clear*)
Tuning Graph<br />
_Laps are not recorded if RSSI does not reach **EnterAt**._
* Lower *EnterAt*

### Missing Laps (Node usually *Crossing*)
Tuning Graph<br />
_Laps are merged together if **ExitAt** is too low, because the first lap crossing never completes._
* Raise *ExitAt*

### Laps register on other parts of a course
Tuning Graph<br />
_Extra crossings occur when **EnterAt** is too low._
* Raise *EnterAt* until *crossings* only begin near the timing gate. (Use the *Marshal* page after saving a race to determine and save the best values.)

### Many laps register at once
Tuning Graph<br />
_Too many laps occur when **ExitAt** is too close to **EnterAt**, because laps exit too quickly._
* Raise *EnterAt*, if possible
* Lower *ExitAt*

The *Minimum Lap Time* setting always keeps the first crossing and disards subsequent laps that occur too soon. In many instances, the second crossing is actually correct, such as when a pilot misses the gate and circles back to complete it. It is recommended to leave the *Minimum Lap Time* behavior at *Highlight* rather than *Discard* so that a race organizer can manually review each case.

### Laps take a long time to register
Tuning Graph<br />
_Lap recording takes a long time to complete if **ExitAt** is low. This does not affect the accuracy of the recorded time._
* Raise *ExitAt*

### Node is never *crossing*
Tuning Graph<br />
_Laps will not register if RSSI never reaches **EnterAt**._
* Lower *EnterAt*

### Node is never *clear*
Tuning Graph<br />
_Laps will not complete if RSSI never drops below **ExitAt**._
* Raise *ExitAt*

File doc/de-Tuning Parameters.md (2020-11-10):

# Kalibrierungs- und Sensorabstimmungsparameter

_Wenn Sie Probleme beim Kalibrieren Ihres Timers haben, stellen Sie sicher, dass Sie die [HF-Abschirmung](de-Shielding%20and%20Course%20Position.md) korrekt konstruiert und platziert haben._

Jeder Knoten verfolgt die Signalstärke (RSSI) auf einer ausgewählten Frequenz und verwendet diese relative Stärke, um zu bestimmen, ob sich ein Sender in der Nähe des Timing-Gates befindet. Mit dem RotorHazard-Zeitmesssystem können Sie jeden Knoten einzeln kalibrieren, um das Verhalten und die Hardwareunterschiede zwischen System und Umgebung auszugleichen.

Ein Knoten kann *Crossing* oder *Clear* sein. Wenn ein Knoten *Clear* ist, glaubt das System, dass sich ein Sender nicht in der Nähe des Timing-Gates befindet, da der RSSI niedrig ist. Wenn es sich um *Crossing* handelt, geht das System davon aus, dass ein Sender am Timing Gate vorbeikommt, da der RSSI hoch ist. Ein Rundenpass wird aufgezeichnet, sobald die *Überfahrt* beendet ist und das System zu *Löschen* zurückkehrt.

Tuning Graph<br />
_RSSI während eines Rennens erscheint ähnlich wie diese Grafik mit vielen sichtbaren Gipfeln und Tälern. Wenn sich der Sender dem Timing-Gate nähert, steigt das Signal an._

## Parameter

Zwei Parameter, die sich auf den Status *Crossing* auswirken: *EnterAt* und *ExitAt*.

### EnterAt

Das System wechselt zu *Crossing*, wenn RSSI auf oder über dieses Niveau steigt. Es wird durch eine rote Linie angezeigt.

### ExitAt

Das System wechselt zu *Löschen*, sobald der RSSI-Wert unter diesen Wert fällt. Es wird durch eine orange Linie angezeigt.

Zwischen *EnterAt* und *ExitAt* bleibt das System je nach vorherigem Status *Crossing* oder *Clear*.

Sample RSSI Graph

### Kalibrierungsmodus

Der *manuelle* Kalibrierungsmodus verwendet immer die vom Benutzer angegebenen Werte *EnterAt* und *ExitAt*.

Der *adaptive* Kalibrierungsmodus verwendet die benutzerdefinierten Punkte, sofern keine Rennen gespeichert sind. Wenn gespeicherte Rennen vorhanden sind, wird durch Ändern der Vorläufe eine Suche in den vorherigen Renndaten nach den besten Kalibrierungswerten für das bevorstehende Rennen eingeleitet. Diese Werte werden kopiert und ersetzen die aktuellen Werte *EnterAt* und *ExitAt* für alle Knoten. Dieser Modus verbessert die Kalibrierung, da mehr Rennen gespeichert werden, wenn der Rennleiter die Anzahl der eingehenden Runden bestätigt oder sie über die Seite *Marschall* neu berechnet.

### Start des Rennens EnterAt/ExitAt Absenkung

Zu Beginn eines Rennens können viele Quads gleichzeitig durch das Starttor fahren, und dies kann dazu führen, dass auf einigen Knoten niedrigere RSSI-Werte erkannt werden (was dazu führen kann, dass ein anfänglicher Gate-Pass verpasst wird). Um dies zu berücksichtigen, können die folgenden Einstellungen konfiguriert werden:

*Start des Rennens EnterAt / ExitAt-Senkungsbetrag (Prozent):* Legt den Betrag fest, um den die EnterAt- und ExitAt-Werte für alle Knoten in Prozent reduziert werden. Wenn beispielsweise 30 (Prozent) konfiguriert ist, wird der EnterAt-Wert auf einen Wert gesenkt, der 30% näher am ExitAt-Wert liegt. (Wenn also EnterAt=90 und ExitAt=80 ist, wird der EnterAt-Wert auf 87 gesenkt.) Der ExitAt-Wert wird ebenfalls um denselben Betrag gesenkt.

*Startbeginn EnterAt / ExitAt-Absenkungsdauer (Sekunden):* Legt die maximale Zeitspanne (in Sekunden) fest, in der die EnterAt- und ExitAt-Werte gesenkt werden. Wenn eine Gate-Kreuzung für einen Knoten vor diesem Zeitpunkt als abgeschlossen erkannt wird, werden die EnterAt- und ExitAt-Werte für diesen Knoten wiederhergestellt.

Vorgeschlagene Werte sind 30 (Prozent) und 10 (Sekunden). Wenn eine dieser Einstellungen als Null konfiguriert ist, werden die EnterAt- und ExitAt-Werte nicht gesenkt.

Beachten Sie, dass auf der Seite *Marschall* diese Einstellungen berücksichtigt werden. Wenn sie also nicht Null sind, wird möglicherweise der erste Rundenpass auf einem Knoten erkannt, obwohl der maximale RSSI-Wert niedriger als der angezeigte EnterAt-Wert zu sein scheint.

## Tuning

Schalten Sie den Timer vor dem Einstellen ein und lassen Sie ihn einige Minuten laufen, damit sich die Empfängermodule erwärmen können. Die RSSI-Werte steigen in der Regel um einige Punkte an, wenn sich der Timer erwärmt.

Auf der Seite *Marschall* können Sie Werte visuell einstellen. Sammeln Sie Daten, indem Sie auf jedem Kanal ein Rennen mit einem Piloten durchführen, und speichern Sie sie dann. Öffnen Sie die Seite *Marschall* und zeigen Sie die Renndaten an. Passen Sie die Ein- und Ausstiegspunkte an, bis die Anzahl der Runden korrekt ist. Speichern Sie die Eingabe- / Ausstiegspunkte auf jedem Knoten, um sie als Kalibrierung für zukünftige Rennen zu verwenden.

### Stellen Sie den Wert *EnterAt* ein

Tuning Graph

* Unterhalb der Spitze aller Torübergänge
* Über jeder Spitze, wenn sich der Sender nicht in der Nähe des Gates befindet
* Höher als *ExitAt*

### Stellen Sie den Wert *ExitAt* ein

Tuning Graph

* Unterhalb von Tälern, die während einer Torüberquerung auftreten
* Über dem niedrigsten Wert, der während einer Runde gesehen wurde
* Niedriger als *EnterAt*

ExitAt-Werte, die näher an EnterAt liegen, ermöglichen es dem Timer, Runden früher anzukündigen und anzuzeigen, können jedoch dazu führen, dass mehrere Runden aufgezeichnet werden.

### Tuning Beispiel

Tuning Graph<br />
_Zwei Runden werden aufgezeichnet. Das Signal steigt über *EnterAt* und fällt dann zweimal unter *ExitAt*, einmal an jedem Peak. Innerhalb dieser beiden Kreuzungsfenster findet der Timer nach der Rauschfilterung das stärkste Signal, das als aufgezeichnete Rundenzeit verwendet werden kann._

### Alternative Tuning Methode

Mit den Schaltflächen *Capture* kann der aktuelle RSSI-Wert als *EnterAt* - oder *ExitAt* -Wert für jeden Knoten gespeichert werden. Die Werte können auch manuell eingegeben und angepasst werden.

Schalten Sie ein Quad auf dem richtigen Kanal ein und bringen Sie es einige Sekunden lang sehr nahe an den Timer. Dadurch kann der Timer den RSSI-Spitzenwert für diesen Knoten erfassen. Dies sollte für jeden Knoten / Kanal erfolgen, der abgestimmt wird. Der Spitzenwert wird angezeigt.

#### EnterAt

Ein guter Ausgangspunkt für *EnterAt* ist die Erfassung des Werts mit einem Quad, das etwa 1,5 bis 3 m vom Timer entfernt ist.

#### ExitAt

Ein guter Ausgangspunkt für *ExitAt* ist die Erfassung des Werts mit einem Quad, das etwa 6 bis 9 m vom Timer entfernt ist.

## Anmerkungen

* Ein niedriger *ExitAt* -Wert kann immer noch ein genaues Timing liefern, aber das System wartet länger, bevor Runden angekündigt werden. Eine Verzögerung bei der Ansage hat keinen Einfluss auf die Genauigkeit des Timers.
* Die Einstellung *Minimale Rundenzeit* kann verwendet werden, um zusätzliche Durchgänge zu verhindern, kann jedoch Kreuzungen maskieren, die zu früh ausgelöst werden. Es wird empfohlen, das Verhalten bei *Hervorheben* anstatt bei *Verwerfen* zu belassen.
* Wenn während eines Rennens Zeitprobleme auftreten und die RSSI-Grafiken auf den Senderstandort reagieren, beenden Sie das Rennen nicht. Speichern Sie das Rennen nach Abschluss und besuchen Sie die Seite *Marschall*. Der gesamte RSSI-Verlauf wird gespeichert und das Rennen kann mit aktualisierten Tuning-Werten genau neu berechnet werden.

## Fehlerbehebung

### Fehlende Runden (System normalerweise *Löschen*)

Tuning Graph<br />
_Runden werden nicht aufgezeichnet, wenn RSSI EnterAt nicht erreicht wurde._

* Senken Sie *EnterAt*

### Fehlende Runden (System normalerweise *Crossing*)

Tuning Graph<br />
_Runden werden zusammengeführt, wenn *ExitAt* zu hoch ist, weil die erste Rundenüberquerung nie abgeschlossen wird._

* Erhöhen Sie *ExitAt*

### Runden registrieren sich für andere Teile eines Kurses

Tuning Graph<br />
_Extra-Kreuzungen treten auf, wenn *EnterAt* zu niedrig ist._

* Erhöhen Sie *EnterAt*, bis *Kreuzungen* erst in der Nähe des Timing-Gates beginnen. (Verwenden Sie nach dem Speichern eines Rennens die Seite *Marschall*, um die besten Werte zu ermitteln und zu speichern.)

### Viele Runden werden gleichzeitig registriert

Tuning Graph<br />
_Zu viele Runden treten auf, wenn *ExitAt* zu nahe an *EnterAt* liegt, weil Runden zu schnell beendet werden._

* Erhöhen Sie nach Möglichkeit *EnterAt*
* Niedriger *ExitAt*

Die Einstellung *Minimale Rundenzeit* behält immer die erste Überfahrt bei und verwirft nachfolgende Runden, die zu früh auftreten. In diesem Fall würde diese Einstellung die richtige erste Kreuzung verwerfen und die falsche zweite Kreuzung beibehalten. Es wird empfohlen, das Verhalten *Minimale Rundenzeit* bei *Hervorheben* anstatt bei *Verwerfen* zu belassen, damit ein Rennveranstalter jeden Fall manuell überprüfen kann.

### Die Registrierung der Runden dauert lange

Tuning Graph<br />
_Die Rundenaufzeichnung dauert lange, wenn *ExiAt* niedrig ist. Dies hat keinen Einfluss auf die Genauigkeit der aufgezeichneten Zeit._

* Erhöhen Sie *ExitAt*

### Der Knoten kreuzt niemals

Tuning Graph<br />
_Laps werden nicht registriert, wenn RSSI *EnterAt* nie erreicht ._

* Senken Sie *EnterAt*

### Der Knoten ist niemals *klar*

Tuning Graph<br />
_Laps werden nicht abgeschlossen, wenn RSSI niemals unter *ExitAt* fällt ._

* Erhöhen Sie *ExitAt*

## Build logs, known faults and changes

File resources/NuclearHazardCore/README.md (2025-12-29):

# NuclearHazard Core Timer

Current hardware version: v8

NuclearHazard Core is a design which allows simple access to RotorHazard timer hardware by allowing it to be populated directly by PCB manufacturers.

[NuclearHazard timer kits are available for purchase](https://nuclearquads.com) from the board designer.

## Features

Instead of a PCB the must be populated with many additional modules, this board uses the bare components to maintain compatibility while being fully assembled by the PCB manufacturer.

- The same STM32 chip as the BluePill board is attached directly to the main NuclearHazard board. Updating the STM32 is easily done through the web interface.
- RX modules are soldered to dual-RX carrier boards, which slot in to connectors on the main board for easy upgrades.
- Fits all **Model A, B, and Zero** Raspberry Pis.
- Power, fan, and LED connectors are included on the main board.
- 2–5S power input (21V recommended max).
- Hardware support for STM32-based RTC (see [Future Provisions](#future-provisions))
- Hardware support for STM32-based VBAT monitoring (see [Future Provisions](#future-provisions))

## Assembly

Before installing the Pi onto the board, install the board in the case and secure with 2–4 screws. Use 4–6mm M3 screws.

When installing the Pi onto the board, line up the 40-pin connector and press both sides evenly. You may use [11mm standoffs](https://www.adafruit.com/product/2336) between the timer board and the Pi, but they are not needed.

The RX module cards can carry 1 or 2 RX5808s. The RotorHazard software will sense (on boot) which solts are filled and work with any number of modules in any slots on the board. Just make sure the cards are inserted correctly (with the dots lined up). 

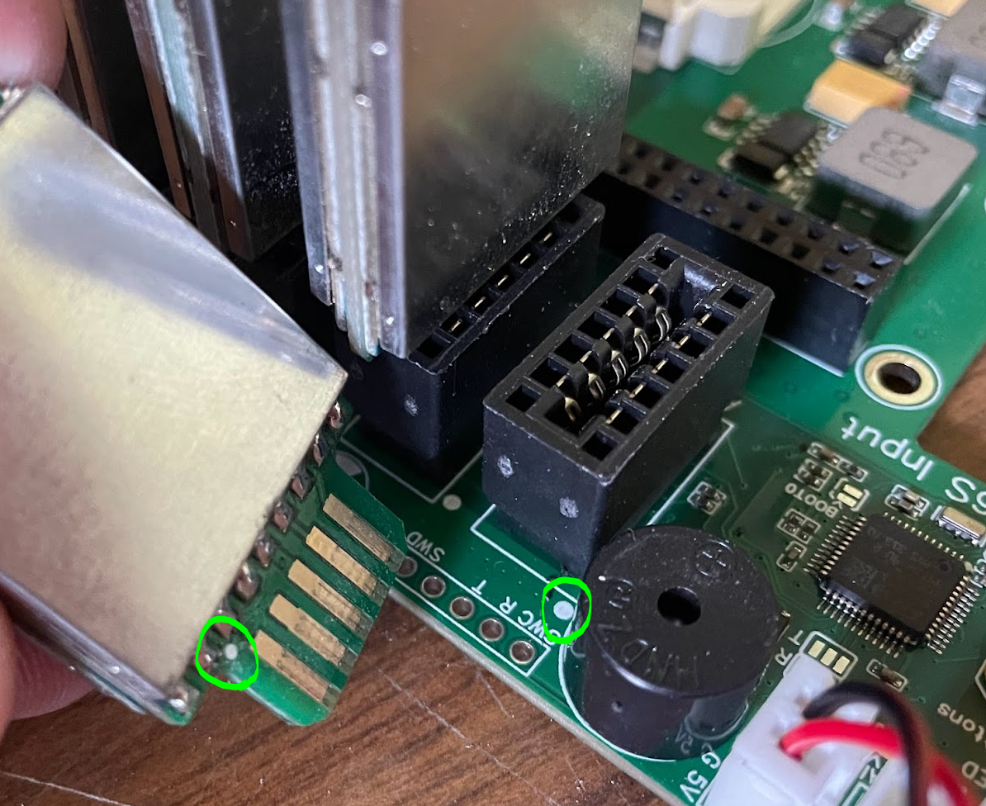
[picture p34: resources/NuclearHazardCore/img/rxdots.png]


If the card is inserted the wrong way, the timer will not be able to set the VRX channel and you'll have bad readings. When adding an RX to a card, be careful to not get solder on the gold plated edge connectors.

The STM32 will need to be flashed after installing the Pi and software. To do so, power the board and use the RH web flashing interface. This board uses a slightly different beeper that needs a line of the node code changed to work. The .bin in the node_src folder has this change. There is also a direct connection for a FTDI adapter to the STM32 to program without the Pi. *If you order a timer from the designer, the latest node code with the buzzer fix will already be uploaded to the STM32.*

## Extra Info

### Voltage regulation

If adding many 5V accessories (LEDs, Fans) try to be concious of the power draw. The 5V regulator on this board is rated for 3A and is already running the Pi and the Fan outputs.

The 3.3V rail is used for the STM, VRXs, and various support components.

### LED plugs

The LED plug is connected to the Pi's **GPIO10** by default and uses a JST-XH connector (the same as a 2S balance connector).

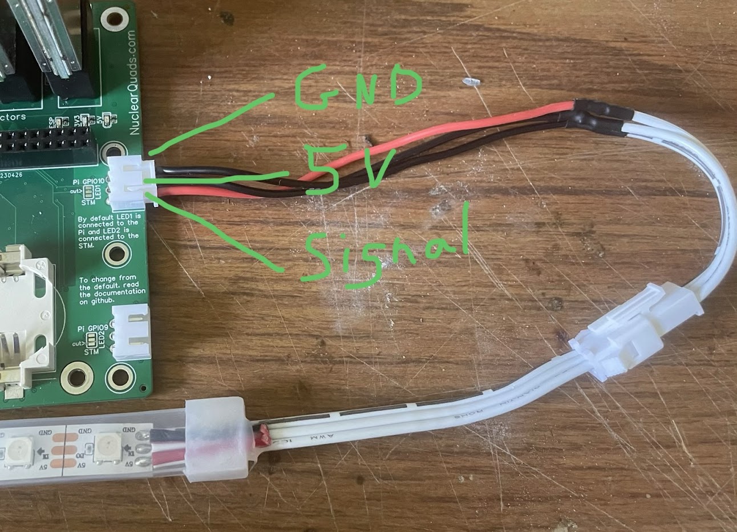
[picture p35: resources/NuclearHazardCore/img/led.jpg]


There are solder jumpers on the PCBs to switch the LED signal pins. For each plug there is a small trace between two of the pads to enable the default connection. If you want to change from the default connection, you'll have to cut the trace between the jumper pads, then add a solder blob from the middle pad to ONE of the outer pins. After making changes to the jumpers but before powering it up, use a multimeter to ensure only one of the outer pads have continuity to the middle pad.

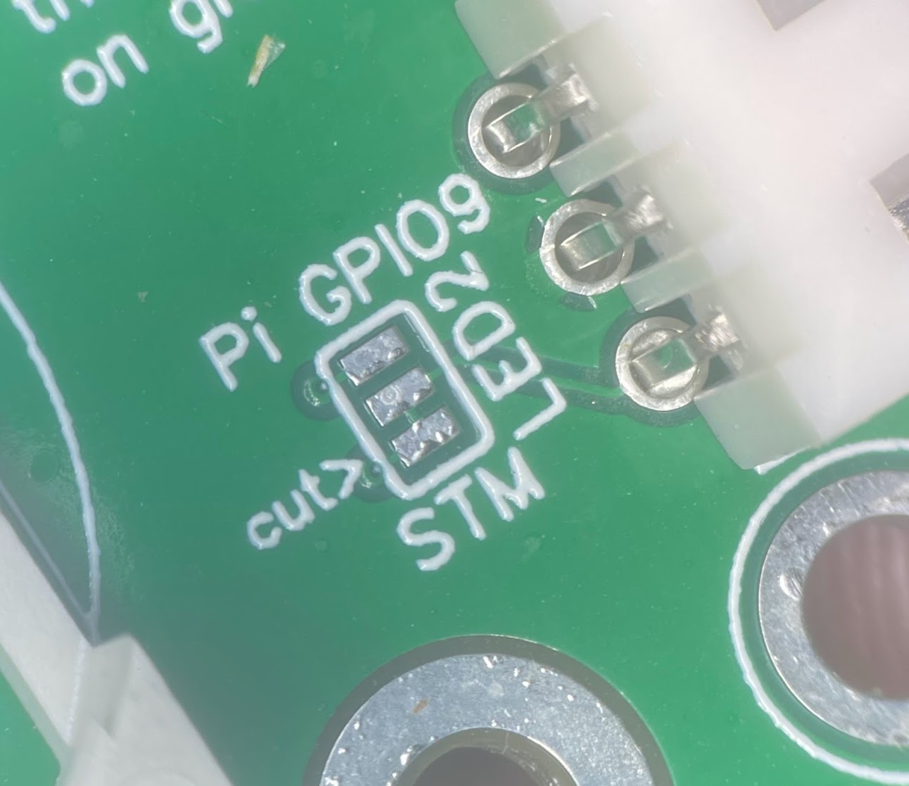
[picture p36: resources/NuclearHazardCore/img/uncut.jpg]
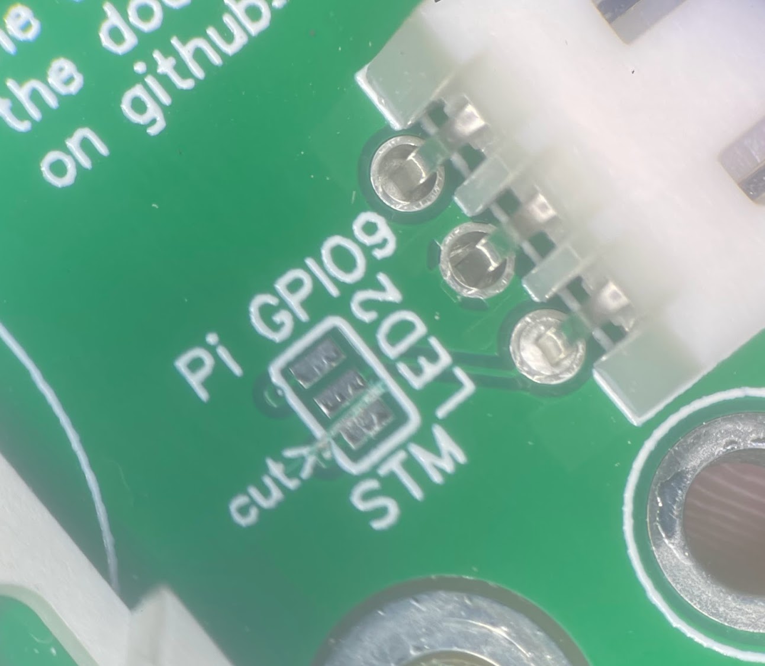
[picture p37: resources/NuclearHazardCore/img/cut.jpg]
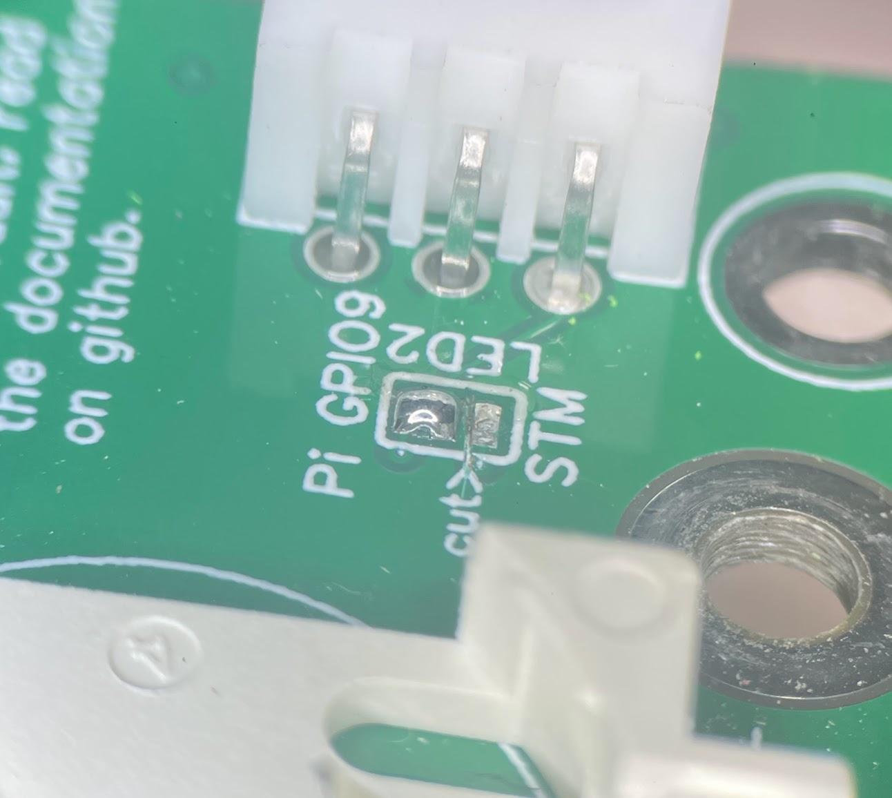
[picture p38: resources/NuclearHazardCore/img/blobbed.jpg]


### Fan connector

The fan connector is a JST-XH and supply 5V any time the Pi is commanding it on. To bypass the Pi control, solder the jumper and it'll always supply 5V. There are polarity markings next to the connector. Make sure your fan matches these. **Pictures on amazon listings for fans should not be trusted.** If needed, repin the fan connector.

### Power connectors

There is a 2.54mm pitch header with the power switch and LED connections marked on the board where a power switch can be added. Use a toggle-type button or switch.

### Ground pad for shielding

There is a ground pad near the RXs that can be used to connect shielding to the board's reference/ground.

## Future Provisions

This board has some hardware features that don't have software support yet. Support may or may not be developed.

### ESP32

There is a footprint for a ESP32-WROOM-32UE module which is connected per the schematic.

### RTC

There is a battery connector that powers the STM32's RTC. Software changes could enable the Pi to boot with the proper time without an internet connection.

### Battery voltage monitoring

There is a voltage divider on the board going from the main power supply to an ADC on the STM32. Software changes could allow this to be reported to the Pi and RotorHazard sensor interface.

## Case

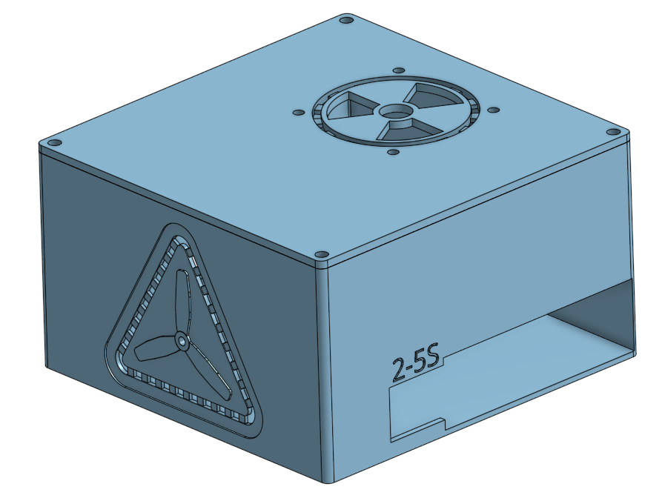
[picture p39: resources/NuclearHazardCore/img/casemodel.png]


To download the most up-to-date 3D model:
1 open the [Onshape project](https://cad.onshape.com/documents/c21f8ac03c166bed0d6faeab/w/4bf3b280307091cb20025cb6/e/3b397b4fdfda612f6dfa1d79) 
2. right click the NuclearHazard tab at the bottom
3. choose export
4. select STL format
5. check "Export unique parts as individual files"
6. click Export

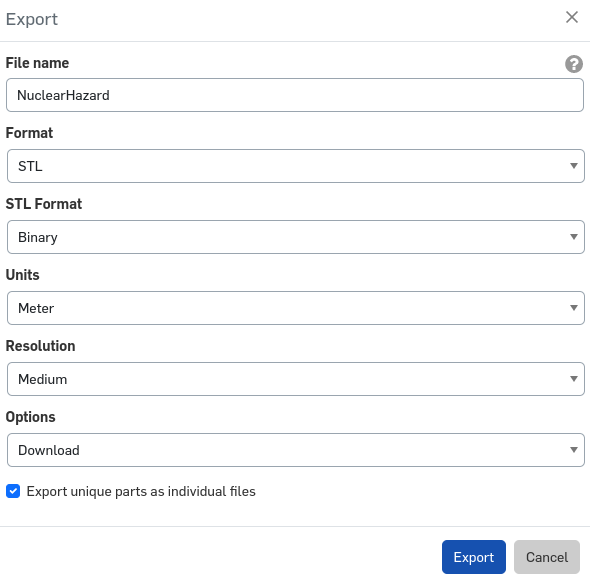
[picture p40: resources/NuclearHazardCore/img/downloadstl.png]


There are two versions of the lid: one for a 40mm fan and one for a 50mm fan.

Print the case with support for only the pi/power hole, sd card cutout, and led headers. Make sure there is no other unnecessary support.

## Troubleshooting

**Can't flash STM32**: Make sure UART is enabled and the 'boot' [config.txt file](https://github.com/RotorHazard/RotorHazard/blob/main/doc/Software%20Setup.md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) is set up.

**RXs won't change channel**: An early batch of RX carrier cards misprinted the alignment dot. Try inserting the carrier cards backwards.

**Shutdown button not working**: For the NuclearHazard PCB, the [shutdown button](https://github.com/RotorHazard/RotorHazard/blob/main/doc/Shutdown%20Button.md) needs to be configured to use GPIO19: On the _Advanced Settings_ page in the _Hardware_ panel, set "Shutdown Button GPIO Number" to 19.

## Schematic

[Schematic](https://github.com/RotorHazard/RotorHazard/blob/main/resources/NuclearHazardCore/pcb/img/Schematic_NuclearHazard.pdf)

## Ordering the PCB

You may order the design files direct from JLCPCB, though it is an involved and technical process.

1. Sign in to [jlcpcb.com](jlcpcb.com)
2. Click "Order Now" on the homepage
3. Upload the NuclearHazard_Gerber.zip file
4. Select your quantity
5. Make sure "PCB Thickness" is "1.6mm"
6. Select "Specify a location" for "Remove Order Number"
7. Enable PCB Assembly
8. Select "Added by Customer" for "Tooling Holes"
9. Verify settings are similar to this screenshot

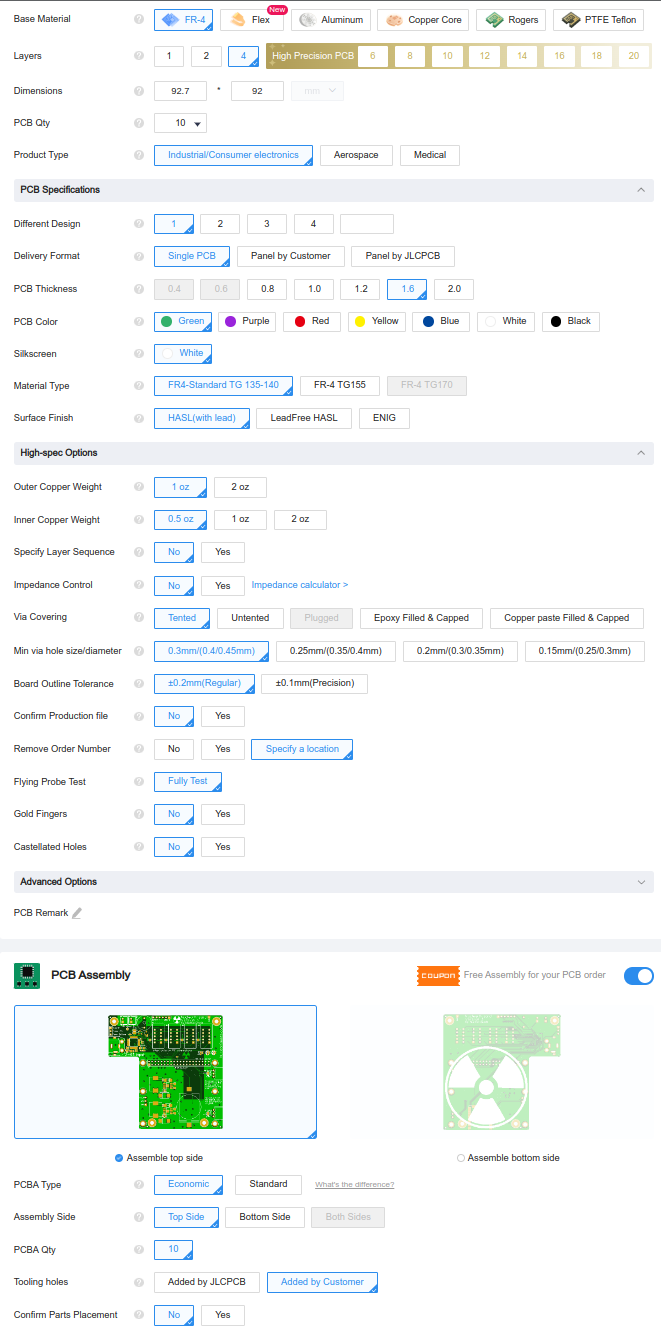
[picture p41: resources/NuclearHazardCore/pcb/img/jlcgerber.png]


10. Click "confirm" at the bottom
11. On the PCB tab just click NEXT
12. On the Bill of Materials tab, upload the BOM and Pick and Place (CPL) files
13. If a part is missing on the BOM list, click search and look for the part number (starts with a C) in the actual BOM file

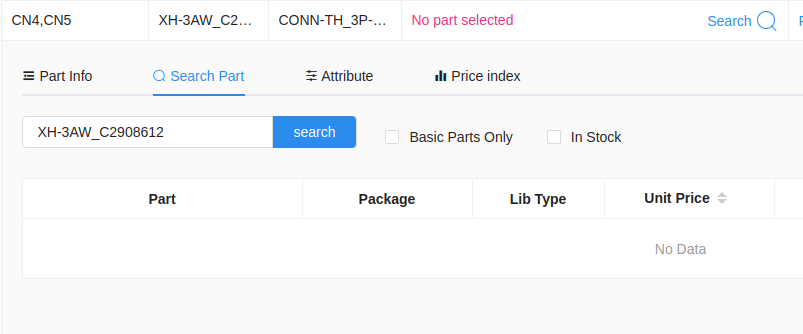
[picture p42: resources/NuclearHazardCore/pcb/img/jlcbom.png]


14. Click NEXT on the component placements tab
15. Select your favorite product description on the right side
16. Click SAVE TO CART
17. Go back to the "Order Now" page and upload the NuclearHazardRXConnector_Gerber.zip file
18. Repeat 4–6
19. Select "ENIG" for "Surface Finish"
20. Select "Yes" for "Gold Fingers"
21. Make sure PCB Assembly is disabled
22. Add to cart

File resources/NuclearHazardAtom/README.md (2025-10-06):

The version most recently sold by NuclearQuads, now discontinued and released as promised.

When ordering from JLCPCB make sure to select:
- 1.6mm PCB
- Assemble bottom side

You'll need to buy separately:
- [2x20 pin female 2.54mm connector](https://www.amazon.com/uxcell-2-54mm-40-Pin-Female-Connector/dp/B00R1LLM1M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) (solder to the side without the XT60)
- [25x25x10mm 5V fan with JST-XH plug](https://www.amazon.com/gp/product/B07KRX9F99/ref=ppx_yo_dt_b_search_asin_title?ie=UTF8&th=1)
- One M3 screw (6-10mm) for the lid
- Pi Zero 2 and SD card

Use the [regular NuclearHazard software setup instructions](https://nuclearquads.github.io/pisetup.html)

Find more info at http://NuclearQuads.com/

Find support at https://discord.gg/ANKd2pzBKH

Find pre-made boards for sale at [NuclearQuads' Store](https://nuclearquads.com)

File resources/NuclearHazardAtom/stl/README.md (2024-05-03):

Download the latest case here from Onshape or use the STLs (may be out of date but should still work).

https://cad.onshape.com/documents/c21f8ac03c166bed0d6faeab/w/4bf3b280307091cb20025cb6/e/96e47cd1bfeece8bc852afed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

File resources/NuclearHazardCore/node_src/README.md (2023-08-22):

This firmware enables the beeper on the NuclearHazard boards. The only change is:

```
--- a/src/node/rhnode.cpp
+++ b/src/node/rhnode.cpp
@@ -645,7 +645,8 @@ void setBuzzerState(bool onFlag)
         {
             currentBuzzerStateFlag = true;
             pinMode(BUZZER_OUTPUT_PIN, OUTPUT);
-            digitalWrite(BUZZER_OUTPUT_PIN, BUZZER_OUT_ONSTATE);
+            //digitalWrite(BUZZER_OUTPUT_PIN, BUZZER_OUT_ONSTATE);
+            analogWrite(BUZZER_OUTPUT_PIN, 512);
```

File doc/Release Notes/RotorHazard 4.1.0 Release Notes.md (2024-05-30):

# RotorHazard 4.1.0 Release Notes

## Highlights

### Support for Raspberry Pi 5
All Pi 5 models are now supported. LEDs cannot (yet) be connected directly to a Pi5, but can be operated using an [LEDCtrlr](https://github.com/RotorHazard/LEDCtrlr) module.

### Performance Optimization
Leaderboard generation time reduced significantly as database size increases, while simultaneously improving system responsiveness during results builds. Gains of over 1100% seen on large databases.

### Improved event and server data handling
Archive and switch events using the `Event` panel. Server configuration is no longer stored in the main database, allowing carryover of server settings while switching events.

### RHAPI 1.1
Includes plugin manifest files; lap add; data attributes for heats, classes, formats, and races; endpoints for server config values. UI for plugins shows what's installed and any failure conditions

### Other Notable Updates
* Additional text variables and documentation
* Split timing improvements
* Security updates, bug fixes, and stability improvements
* Expanded data communications with FPVTrackSide (which enable adaptive calibration)
* Marshaling UI updates; visible frequency info; adjusting values recalculates
* Improved notification of network communications issues
* Updated NuclearHazard build files and Atom
* Periodic sensor logging
* Schedule Race shortcut key (s)
* LED subsystem improvements
* Updated frequency reference includes O3
* Japanese localization
* Documentation updates

## Documentation
Documentation for RotorHazard may be found at:
https://github.com/RotorHazard/RotorHazard/tree/v4.1.0/doc

## Installation / Upgrade Notes

> [!TIP]
> [RotorHazard Install Manager](https://github.com/RotorHazard/RH_Install-Manager) is generally able to install new beta versions within a few hours of release.

To install RotorHazard on a new system, see the instructions in '[doc/Software Setup.md](https://github.com/RotorHazard/RotorHazard/blob/v4.1.0/doc/Software%20Setup.md)'

To update an existing RotorHazard installation, see [Updating an Existing Installation](https://github.com/RotorHazard/RotorHazard/blob/v4.1.0/doc/Software%20Setup.md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). The current version code is `4.1.0`.

The minimum version of Python supported is now 3.8. If your Python is older than this, you should upgrade using the steps in the Software Setup document under "5. [Install Python](https://github.com/RotorHazard/RotorHazard/blob/main/doc/Software%20Setup.md#5-install-python)." or set up a new environment. Do this before updating RotorHazard, or the update may fail.

## RotorHazard Node Code
The node-code version is now 1.1.5 (introduced in 4.1.0-beta.1). Doing a reflash on your node processor is recommended if you're using a board that has an STM32-type processor (optional for Arduino-based boards).

For STM32-based boards, the recommended method for installing the node firmware is to use the Update Nodes button (in the 'System' section on the 'Settings' page) on the RotorHazard web GUI.

## Known Issues
- Renaming a heat will not update the cached "source" display name for fastest lap and consecutives.

## Issue Reporting
If you encounter a bug, please report it using the [Issues page on GitHub](https://github.com/RotorHazard/RotorHazard/issues). When reporting issues, using the "Download Logs" button and including the generated '.zip' file is highly recommended (see below).

The Server Log may be displayed via the "View Server Log" item in the drop-down menu. Clicking on the "Select Text" button will select all the displayed log text, which may then be copied and pasted. Clicking on the "Download Logs" button will create and download a '.zip' archive file containing all available log files and the current configuration and database files.

## What's Changed
* Add v5 nuclearhazard files by @SpencerGraffunder in https://github.com/RotorHazard/RotorHazard/pull/802
* Eliminate dependency "six" by @HazardCreative in https://github.com/RotorHazard/RotorHazard/pull/805
* Bump minimum python version to 3.8 by @HazardCreative in https://github.com/RotorHazard/RotorHazard/pull/806
* Fix LED displays by @HazardCreative in https://github.com/RotorHazard/RotorHazard/pull/807
* Split timer improvements (nameOnly option, etc) by @ethomas997 in https://github.com/RotorHazard/RotorHazard/pull/811
* Remove hard-coded panel size from row inversion by @HazardCreative in https://github.com/RotorHazard/RotorHazard/pull/817
* Software Setup doc updates for venv etc by @ethomas997 in https://github.com/RotorHazard/RotorHazard/pull/815
* RH4 Event setup guide updates by @ethomas997 in https://github.com/RotorHazard/RotorHazard/pull/818
* Log absolute timestamps for race events by @ethomas997 in https://github.com/RotorHazard/RotorHazard/pull/820
* Add Schedule Race shortcut by @HazardCreative in https://github.com/RotorHazard/RotorHazard/pull/813
* Documentation updates for RH4 by @HazardCreative in https://github.com/RotorHazard/RotorHazard/pull/821
* Improved plugins handling/logging when no Pillow library by @ethomas997 in https://github.com/RotorHazard/RotorHazard/pull/828
* add Simplified Chinese localization by @L1cardo in https://github.com/RotorHazard/RotorHazard/pull/826
* Add custom UI panels to streams page by @klaasnicolaas in https://github.com/RotorHazard/RotorHazard/pull/824
* Database as "Event" UI paradigm by @HazardCreative in https://github.com/RotorHazard/RotorHazard/pull/827
* migrate getsize to getbbox by @HazardCreative in https://github.com/RotorHazard/RotorHazard/pull/829
* RHAPI lap_add by @HazardCreative in https://github.com/RotorHazard/RotorHazard/pull/814
* Cleanup unreachable code by @HazardCreative in https://github.com/RotorHazard/RotorHazard/pull/835
* Dependency cleanup by @HazardCreative in https://github.com/RotorHazard/RotorHazard/pull/831
* Marshaling UI updates by @HazardCreative in https://github.com/RotorHazard/RotorHazard/pull/832
* Data attributes for heats, classes, and races (meta) by @HazardCreative in https://github.com/RotorHazard/RotorHazard/pull/836
* Add support for TIME_BEHIND callout variable by @ethomas997 in https://github.com/RotorHazard/RotorHazard/pull/833
* Add 'Clear Messages' action by @ethomas997 in https://github.com/RotorHazard/RotorHazard/pull/834
* Basic Plugin UI by @HazardCreative in https://github.com/RotorHazard/RotorHazard/pull/837
* Raceformat data attributes by @HazardCreative in https://github.com/RotorHazard/RotorHazard/pull/839
* Apply generate parameters as class attribute by @HazardCreative in https://github.com/RotorHazard/RotorHazard/pull/838
* Added format button to home page. by @vikibaarathi in https://github.com/RotorHazard/RotorHazard/pull/841
* Improve frontend status displays by @HazardCreative in https://github.com/RotorHazard/RotorHazard/pull/842
* RH_GPIO abstraction layer by @ethomas997 in https://github.com/RotorHazard/RotorHazard/pull/847
* Pi 5 support by @ethomas997 in https://github.com/RotorHazard/RotorHazard/pull/848
* Update node code to version 1.1.5 by @ethomas997 in https://github.com/RotorHazard/RotorHazard/pull/849
* Temporally remove Chinese localization by @L1cardo in https://github.com/RotorHazard/RotorHazard/pull/845
* Only display stream seats with frequency enabled by @HazardCreative in https://github.com/RotorHazard/RotorHazard/pull/843
* Periodic sensor logging by @HazardCreative in https://github.com/RotorHazard/RotorHazard/pull/844
* Fix sequential assumption for dataloggers by @HazardCreative in https://github.com/RotorHazard/RotorHazard/pull/851
* UI improvements by @HazardCreative in https://github.com/RotorHazard/RotorHazard/pull/852
* Remove event handler kill and prevent LED shutdown by @HazardCreative in https://github.com/RotorHazard/RotorHazard/pull/853
* Updates for Flask and SqlAlchemy libraries / usage by @ethomas997 in https://github.com/RotorHazard/RotorHazard/pull/861
* Added O3 frequency band, as well as the new frequency chart by @eduardorcosta in https://github.com/RotorHazard/RotorHazard/pull/859
* Add support for LEDCtrlr by @ethomas997 in https://github.com/RotorHazard/RotorHazard/pull/871
* Add pilot-frequency info to Marshal page by @ethomas997 in https://github.com/RotorHazard/RotorHazard/pull/873
* Expand returned server info to TrackSide by @HazardCreative in https://github.com/RotorHazard/RotorHazard/pull/863
* Add Japanese localization by @ToshihiroMakuuchi in https://github.com/RotorHazard/RotorHazard/pull/870
* Fixes for database connections building up by @ethomas997 in https://github.com/RotorHazard/RotorHazard/pull/876
* Japanese localization fixes by @ToshihiroMakuuchi in https://github.com/RotorHazard/RotorHazard/pull/877
* Add import/export for Audio Settings by @ethomas997 in https://github.com/RotorHazard/RotorHazard/pull/879
* Japanese localization fixex (v4.1.0-beta2) by @ToshihiroMakuuchi in https://github.com/RotorHazard/RotorHazard/pull/884
* Record race history when initiated from FPVTrackSide by @eedok in https://github.com/RotorHazard/RotorHazard/pull/885
* Migrate config to class and provide API endpoints by @HazardCreative in https://github.com/RotorHazard/RotorHazard/pull/869
* Improved gevent.sleep/thread management by @ethomas997 in https://github.com/RotorHazard/RotorHazard/pull/887
* Results optimization by @HazardCreative in https://github.com/RotorHazard/RotorHazard/pull/895
* Single Pass Mapping by @i-am-grub in https://github.com/RotorHazard/RotorHazard/pull/897
* Add NuclearHazard Atom PCB files by @SpencerGraffunder in https://github.com/RotorHazard/RotorHazard/pull/898
* Japanese localization additional fix02 by @ToshihiroMakuuchi in https://github.com/RotorHazard/RotorHazard/pull/894
* Fix issue with switching from 'None' to pilot in heat by @ethomas997 in https://github.com/RotorHazard/RotorHazard/pull/908

## New Contributors
* @L1cardo made their first contribution in https://github.com/RotorHazard/RotorHazard/pull/826
* @eduardorcosta made their first contribution in https://github.com/RotorHazard/RotorHazard/pull/859
* @ToshihiroMakuuchi made their first contribution in https://github.com/RotorHazard/RotorHazard/pull/870
* @eedok made their first contribution in https://github.com/RotorHazard/RotorHazard/pull/885
* @i-am-grub made their first contribution in https://github.com/RotorHazard/RotorHazard/pull/897

**Full Changelog**: https://github.com/RotorHazard/RotorHazard/compare/v4.0.1...v4.1.0

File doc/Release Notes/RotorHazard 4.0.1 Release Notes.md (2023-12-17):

# RotorHazard 4.0.1 Release Notes

## Updates since v4.0.0

* Software Setup doc updates for venv etc (#815)
* Updated Event Setup Guide (#818)
* Updated User Guide
* Fixed leader proxy and RHAPI call for LED displays (#807)
* Fixed to prevent potential stall of speak queue processing
* Added Schedule Race shortcut key ('S')
* Improved plugins handling/logging when no Pillow library (#828)
* Eliminate dependency on "six" library (#805)

See the [release notes from v4.0.0](https://github.com/RotorHazard/RotorHazard/releases/tag/v4.0.0) for a list of the v4.0.0 changes since the v3.2.2 release. Full Changelog: https://github.com/RotorHazard/RotorHazard/compare/v3.2.0...v4.0.1

## Compatibility
RotorHazard v4.0.0 and later use an updated version of the socket library which is not compatible with releases before v4.0.0. All timers in a cluster (secondary/split timers, mirror timers) and socket-based interfaces must be updated to match. Because of this upgrade away from outdated and insecure code, **Delta5 emulation has ended with RotorHazard 3.2**.

## Documentation
Documentation for RotorHazard 4.0.1 may be found at:
https://github.com/RotorHazard/RotorHazard/tree/v4.0.1/doc

## Installation / Upgrade Notes
To install RotorHazard on a new system, see the instructions in '[doc/Software Setup.md](https://github.com/RotorHazard/RotorHazard/blob/v4.0.1/doc/Software%20Setup.md)'

To update an existing RotorHazard installation, see [Updating an Existing Installation](https://github.com/RotorHazard/RotorHazard/blob/v4.0.1/doc/Software%20Setup.md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). The current version code is `4.0.1`

## RotorHazard Node Code
No updates to the node code have been made since RotorHazard version 3.0.0 (the node-code version is 1.1.4).

## Issues
If you encounter a bug, please report it using the [Issues page on GitHub](https://github.com/RotorHazard/RotorHazard/issues). When reporting issues, using the "Download Logs" button and including the generated '.zip' file is highly recommended (see below).

The Server Log may be displayed via the "View Server Log" item in the drop-down menu. Clicking on the "Select Text" button will select all the displayed log text, which may then be copied and pasted. Clicking on the "Download Logs" button will create and download a '.zip' archive file containing all available log files and the current configuration and database files.

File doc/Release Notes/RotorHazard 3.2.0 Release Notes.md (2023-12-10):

# RotorHazard 3.2.0 Release Notes

## New features and important fixes

### New race format extensions
Extended staging sequence options allow more control of staging tones and random delay. Laps stop automatically counting once a race concludes. Automatic race stop after configurable grace period.

### Actions
Assign effects to timer events to automate common tasks. For example, assign speech to the "pilot done" event for automatic announcement of each pilot's end. Available action effects will be extended in future versions, and plugins may supply new effects.

### Plugins
Load plugins to extend server capabilities. Plugins can interface with standard timer events, LED effects, data exporters, and Actions. See [Plugin documentation](https://github.com/RotorHazard/RotorHazard/blob/v3.2.0/doc/Plugins.md) for more information.

### Performance and UX improvements
Faster page load for marshaling, view time elapsed after race clock ends, simpler race stop/save/advance procedures, automatic speech synthesis enabling, manual retries for secondary connections, improved documentation

## Detailed updates from RotorHazard 3.1
* Add last-lap grace period #500 #502 #669 #671
* Two-phase staging (improved start sequence) #646 #665
* Add user-defined event Actions #670
* Add global plugin system #684
    * Load plugins from ./plugins directory
    * Call each [plugin].initialize() to register hooks and event handlers
    * Make LED handlers, data exporters, and Action Effects pluggable
    * Migrate LED handlers and data exporters to plugins
* Add Manual retry for secondary connection #688
* Conditionally announce laps after pilot done #675 #680
* Improve marshaling page load time #390 #666
* Allow stopping race with save+clear #363 #668
* Time counts negative after race end #574 #663
* Add Race Leader announcement #694
* Add "Show late lap" option to Current Race page #695
* Browser clock optimization #683
* Fix arbitrary file read vulnerability #649 #650 #662
* Initialize speech synthesis on page interaction (fixes audio on iOS) #419 #661
* Fix %HEAT% token replacement in manual callout #606 #660 -- Thank you, [andreyzher](https://github.com/andreyzher)
* Extended pause between %PILOTS% %607 #664
* Clarify LED setup (LED_PIN -> LED_GPIO) #667
* Add delete button to callouts #682
* Fix unintended min_lap highlight on Current
* Update frequency reference
* Update LED library for newer hardware
* Update dependency versions #678 #681 #687
* Option to hide RSSI graphing from Run UI #689 
* Fix frontend load issue
* Set gitignore appropriately for plugins
* Update documentation
* Improve staging labeling and documentation #690 
* Bug fixes and stability improvements

## Documentation
Documentation for RotorHazard 3.2.0 may be found at:
https://github.com/RotorHazard/RotorHazard/tree/v3.2.0/doc

## Installation / Upgrade Notes
To install RotorHazard on a new system, see the instructions in '[doc/Software Setup.md](https://github.com/RotorHazard/RotorHazard/blob/v3.2.0/doc/Software%20Setup.md)'

To update an existing RotorHazard installation to this version:
```
cd ~
wget https://codeload.github.com/RotorHazard/RotorHazard/zip/v3.2.0 -O temp.zip
unzip temp.zip
mv RotorHazard RotorHazard.old
mv RotorHazard-3.2.0 RotorHazard
rm temp.zip
cp RotorHazard.old/src/server/config.json RotorHazard/src/server/
cp RotorHazard.old/src/server/database.db RotorHazard/src/server/
```
The previous installation ends up in the 'RotorHazard.old' directory, which may be deleted or moved.

The minimum version of Python supported is 3.5. If your Python is older than this, you should upgrade using the steps in the Software Setup document under "5. [Install Python](https://github.com/RotorHazard/RotorHazard/blob/main/doc/Software%20Setup.md#5-install-python)."

The RotorHazard server dependencies should also be updated (be patient, this command may take a few minutes):
```
cd ~/RotorHazard/src/server
sudo pip install --upgrade --no-cache-dir -r requirements.txt
```

## RotorHazard Node Code
No updates to the node code have been made since RotorHazard version 3.0.0 (the node-code version is 1.1.4).

## Issues
If you encounter a bug, please report it using the [Issues page on GitHub](https://github.com/RotorHazard/RotorHazard/issues). When reporting issues, using the "Download Logs" button and including the generated '.zip' file is highly recommended (see below).

The Server Log may be displayed via the "View Server Log" item in the drop-down menu. Clicking on the "Select Text" button will select all the displayed log text, which may then be copied and pasted. Clicking on the "Download Logs" button will create and download a '.zip' archive file containing all available log files and the current configuration and database files.

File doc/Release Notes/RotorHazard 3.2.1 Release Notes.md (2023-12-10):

# RotorHazard 3.2.1 Release Notes

## Updates since 3.2.0

* Fixed issue preventing saving active race.

See [release notes from 3.2.0](RotorHazard%203.2.0%20Release%20Notes.md) for more information on this version.

## Documentation
Documentation for RotorHazard 3.2.1 may be found at:
https://github.com/RotorHazard/RotorHazard/tree/v3.2.1/doc

## Installation / Upgrade Notes
To install RotorHazard on a new system, see the instructions in '[doc/Software Setup.md](https://github.com/RotorHazard/RotorHazard/blob/v3.2.1/doc/Software%20Setup.md)'

To update an existing RotorHazard installation to this version:
```
cd ~
wget https://codeload.github.com/RotorHazard/RotorHazard/zip/v3.2.1 -O temp.zip
unzip temp.zip
mv RotorHazard RotorHazard.old
mv RotorHazard-3.2.1 RotorHazard
rm temp.zip
cp RotorHazard.old/src/server/config.json RotorHazard/src/server/
cp RotorHazard.old/src/server/database.db RotorHazard/src/server/
```
The previous installation ends up in the 'RotorHazard.old' directory, which may be deleted or moved.

The minimum version of Python supported is 3.5. If your Python is older than this, you should upgrade using the steps in the Software Setup document under "5. [Install Python](https://github.com/RotorHazard/RotorHazard/blob/main/doc/Software%20Setup.md#5-install-python)."

## RotorHazard Node Code
No updates to the node code have been made since RotorHazard version 3.0.0 (the node-code version is 1.1.4).

## Issues
If you encounter a bug, please report it using the [Issues page on GitHub](https://github.com/RotorHazard/RotorHazard/issues). When reporting issues, using the "Download Logs" button and including the generated '.zip' file is highly recommended (see below).

The Server Log may be displayed via the "View Server Log" item in the drop-down menu. Clicking on the "Select Text" button will select all the displayed log text, which may then be copied and pasted. Clicking on the "Download Logs" button will create and download a '.zip' archive file containing all available log files and the current configuration and database files.

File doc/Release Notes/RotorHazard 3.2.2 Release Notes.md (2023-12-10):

# RotorHazard 3.2.2 Release Notes

## Updates since [3.2.1](RotorHazard%203.2.1%20Release%20Notes.md)

* Added zero-delay staging when race is started via Delta5 emulation (fixes short holeshots LiveTime)
* Supply a consistent zero point for Delta5 emulation (LiveTime results now exactly match RotorHazard results)
* Fixed marshaling a race with no/secondary format
* Fixed stopping a race multiple times
* Fixed announcing an unassigned pilot

See [release notes from 3.2.0](RotorHazard%203.2.0%20Release%20Notes.md) for more information on this version.

Full Changelog: https://github.com/RotorHazard/RotorHazard/compare/v3.2.1...v3.2.2

## Documentation
Documentation for RotorHazard 3.2.2 may be found at:
https://github.com/RotorHazard/RotorHazard/tree/v3.2.2/doc

## Installation / Upgrade Notes
To install RotorHazard on a new system, see the instructions in '[doc/Software Setup.md](https://github.com/RotorHazard/RotorHazard/blob/v3.2.2/doc/Software%20Setup.md)'

To update an existing RotorHazard installation to this version:
```
cd ~
wget https://codeload.github.com/RotorHazard/RotorHazard/zip/v3.2.2 -O temp.zip
unzip temp.zip
mv RotorHazard RotorHazard.old
mv RotorHazard-3.2.2 RotorHazard
rm temp.zip
cp RotorHazard.old/src/server/config.json RotorHazard/src/server/
cp RotorHazard.old/src/server/database.db RotorHazard/src/server/
```
The previous installation ends up in the 'RotorHazard.old' directory, which may be deleted or moved.

The minimum version of Python supported is 3.5. If your Python is older than this, you should upgrade using the steps in the Software Setup document under "5. [Install Python](https://github.com/RotorHazard/RotorHazard/blob/main/doc/Software%20Setup.md#5-install-python)."

## RotorHazard Node Code
No updates to the node code have been made since RotorHazard version 3.0.0 (the node-code version is 1.1.4).

## Issues
If you encounter a bug, please report it using the [Issues page on GitHub](https://github.com/RotorHazard/RotorHazard/issues). When reporting issues, using the "Download Logs" button and including the generated '.zip' file is highly recommended (see below).

The Server Log may be displayed via the "View Server Log" item in the drop-down menu. Clicking on the "Select Text" button will select all the displayed log text, which may then be copied and pasted. Clicking on the "Download Logs" button will create and download a '.zip' archive file containing all available log files and the current configuration and database files.

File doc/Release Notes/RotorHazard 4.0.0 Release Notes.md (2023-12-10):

# RotorHazard 4.0.0 Release Notes

## Highlights

### Auto Seeding and Frequency Management
Seed heats based on the results of any heat or class, allowing event formats automatically driven by pilot performance. When seeding, it intelligently minimizes frequency changes and uses event history to reduce the need for re-calibrations.

### Heat Generation, Race Points
Generate popular event formats including ladder (letter) mains and regulation (FAI, MultiGP) single- and double-elimination brackets, which run with automatic seeding and frequency management. Fill heats randomly for qualifying while balancing the number of pilots in each. Award points for finishing position. New heat generators and points methods may be added by plugins.

### Class Ranking
Rank performance by best X rounds, last heat position (for ladders), or cumulative points. New class ranking methods may be added by plugins.

### Extended Plugin Reach and API
New methods provide easy access and greatly extend the reach of plugins. A new API introduces a stable method to access data and functions, providing plugin authors with the capability to significantly extend functionality. See [Plugins](/doc/Plugins.md).

### New Low-Cost Build Option
Spencer Graffunder's NuclearHazard is designed to allow components to be populated at the factory, reducing costs, size, and build time.

### Other Notable Updates
* FPVTrackSide support
* Pilotless practice mode
* Variable consecutive laps base
* Message center
* Secondary timer action mode
* Bug fixes, stability upgrades, and performance upgrades

## Compatibility
This version uses an updated version of the socket library which is not compatible with previous RotorHazard releases. All timers in a cluster (mirrors, split timers) and socket-based interfaces must be updated to match. Because of this upgrade away from outdated and insecure code, **Delta5 emulation has ended with RotorHazard 3.2**.

## Documentation
Documentation for RotorHazard 4.0.0 may be found at:
https://github.com/RotorHazard/RotorHazard/tree/v4.0.0/doc

## Installation / Upgrade Notes
To install RotorHazard on a new system, see the instructions in '[doc/Software Setup.md](https://github.com/RotorHazard/RotorHazard/blob/v4.0.0/doc/Software%20Setup.md)'

To update an existing RotorHazard installation, see [Updating an Existing Installation](https://github.com/RotorHazard/RotorHazard/blob/v4.0.0/doc/Software%20Setup.md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). The current version code is `4.0.0`.

## RotorHazard Node Code
No updates to the node code have been made since RotorHazard version 3.0.0 (the node-code version is 1.1.4).

## Issues
If you encounter a bug, please report it using the [Issues page on GitHub](https://github.com/RotorHazard/RotorHazard/issues). When reporting issues, using the "Download Logs" button and including the generated '.zip' file is highly recommended (see below).

The Server Log may be displayed via the "View Server Log" item in the drop-down menu. Clicking on the "Select Text" button will select all the displayed log text, which may then be copied and pasted. Clicking on the "Download Logs" button will create and download a '.zip' archive file containing all available log files and the current configuration and database files.

## Detailed updates from 3.2
* Event Structure by @HazardCreative in https://github.com/RotorHazard/RotorHazard/pull/699
* Use InvokeFnQueue with 'pass_record_callback' and 'check_win_condition' by @ethomas997 in https://github.com/RotorHazard/RotorHazard/pull/700
* RHData 'restore_table' improvements by @ethomas997 in https://github.com/RotorHazard/RotorHazard/pull/701
* Event structure support by @HazardCreative in https://github.com/RotorHazard/RotorHazard/pull/705
* Update doc on PCB for 6 arduinos by @laurent-clouet in https://github.com/RotorHazard/RotorHazard/pull/702
* Update Software Setup.md by @MacDaddyFPV in https://github.com/RotorHazard/RotorHazard/pull/710
* Event structure UI, cleanup, and stability by @HazardCreative in https://github.com/RotorHazard/RotorHazard/pull/711
* Re-implement VRx Control as Manager/Controller; enabling plugins by @HazardCreative in https://github.com/RotorHazard/RotorHazard/pull/721
* Stream node display misalignment by @vikibaarathi in https://github.com/RotorHazard/RotorHazard/pull/722
* RHRace cleanup by @HazardCreative in https://github.com/RotorHazard/RotorHazard/pull/726
* RHData resolvers by @HazardCreative in https://github.com/RotorHazard/RotorHazard/pull/727
* Expand User Interface class by @HazardCreative in https://github.com/RotorHazard/RotorHazard/pull/728
* Shared race context by @HazardCreative in https://github.com/RotorHazard/RotorHazard/pull/730
* Fixed calling wrong query to get race format ID by @vikibaarathi in https://github.com/RotorHazard/RotorHazard/pull/736
* Message center for server messages by @HazardCreative in https://github.com/RotorHazard/RotorHazard/pull/737
* Updated sample path for fresh install lang by @vikibaarathi in https://github.com/RotorHazard/RotorHazard/pull/738
* Global color enable by @HazardCreative in https://github.com/RotorHazard/RotorHazard/pull/739
* Fix UI focus issue by @HazardCreative in https://github.com/RotorHazard/RotorHazard/pull/740
* Variable consecutive laps base by @HazardCreative in https://github.com/RotorHazard/RotorHazard/pull/741
* Frontend parameter UI by @HazardCreative in https://github.com/RotorHazard/RotorHazard/pull/745
* Add margin to elements in pilot form by @vikibaarathi in https://github.com/RotorHazard/RotorHazard/pull/742
* Improve french language by @arnaudmorin in https://github.com/RotorHazard/RotorHazard/pull/750
* Pluggable class rank by @HazardCreative in https://github.com/RotorHazard/RotorHazard/pull/747
* Data import by @HazardCreative in https://github.com/RotorHazard/RotorHazard/pull/748
* Fix /api/race/current return json by @arnaudmorin in https://github.com/RotorHazard/RotorHazard/pull/754
* Frequency aware adaptive calibration by @HazardCreative in https://github.com/RotorHazard/RotorHazard/pull/749
* Update jquery and socket-io versions by @ethomas997 in https://github.com/RotorHazard/RotorHazard/pull/752
* Schedule race action by @HazardCreative in https://github.com/RotorHazard/RotorHazard/pull/755
* Points-based ranking by @HazardCreative in https://github.com/RotorHazard/RotorHazard/pull/757
* Add DJI freqs in IMDtabler tables by @arnaudmorin in https://github.com/RotorHazard/RotorHazard/pull/753
* Replace plugin interfaces with RHAPI by @HazardCreative in https://github.com/RotorHazard/RotorHazard/pull/759
* PEP8 refactoring by @HazardCreative in https://github.com/RotorHazard/RotorHazard/pull/762
* Event / callout improvements by @ethomas997 in https://github.com/RotorHazard/RotorHazard/pull/765
* Plugin exception handling by @HazardCreative in https://github.com/RotorHazard/RotorHazard/pull/758
* RHAPI Expansion by @HazardCreative in https://github.com/RotorHazard/RotorHazard/pull/767
* Fixed race duration field toggle when no time limit by @vikibaarathi in https://github.com/RotorHazard/RotorHazard/pull/770
* Improved race-leader detection by @ethomas997 in https://github.com/RotorHazard/RotorHazard/pull/771
* Added secondary timer 'action' mode by @ethomas997 in https://github.com/RotorHazard/RotorHazard/pull/772
* Check/create heat on secondary timer if needed by @ethomas997 in https://github.com/RotorHazard/RotorHazard/pull/776
* Add NuclearHazard files by @SpencerGraffunder in https://github.com/RotorHazard/RotorHazard/pull/764
* Next round marker by @HazardCreative in https://github.com/RotorHazard/RotorHazard/pull/778
* FPVTrackSide connector by @HazardCreative in https://github.com/RotorHazard/RotorHazard/pull/777
* Split/speed timer improvements by @ethomas997 in https://github.com/RotorHazard/RotorHazard/pull/781
* Add fastest-speed callout variables by @ethomas997 in https://github.com/RotorHazard/RotorHazard/pull/782
* Allow speed callouts outside of race laps by @ethomas997 in https://github.com/RotorHazard/RotorHazard/pull/791
* RHAPI/Event expansion by @HazardCreative in https://github.com/RotorHazard/RotorHazard/pull/790

### New Contributors
* @laurent-clouet made their first contribution in https://github.com/RotorHazard/RotorHazard/pull/702
* @MacDaddyFPV made their first contribution in https://github.com/RotorHazard/RotorHazard/pull/710
* @vikibaarathi made their first contribution in https://github.com/RotorHazard/RotorHazard/pull/722
* @arnaudmorin made their first contribution in https://github.com/RotorHazard/RotorHazard/pull/750
* @SpencerGraffunder made their first contribution in https://github.com/RotorHazard/RotorHazard/pull/764

Full Changelog: https://github.com/RotorHazard/RotorHazard/compare/v3.2.0...v4.0.0

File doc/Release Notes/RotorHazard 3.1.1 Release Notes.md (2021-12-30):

# RotorHazard 3.1.1 Release Notes

## Updates since 3.1.0

 * Fixed issue adding nodes to existing setup #637

See [release notes from 3.1.0](https://github.com/RotorHazard/RotorHazard/releases/tag/3.1.0) for more information on this version.

## Documentation

Documentation for RotorHazard 3.1.1 may be found at:
https://github.com/RotorHazard/RotorHazard/tree/3.1.1/doc

## Installation / Upgrade Notes

To install RotorHazard on a new system, see the instructions in '[doc/Software Setup.md](https://github.com/RotorHazard/RotorHazard/blob/3.1.1/doc/Software%20Setup.md)'

To update an existing RotorHazard installation to this version:
```
cd ~
wget https://codeload.github.com/RotorHazard/RotorHazard/zip/3.1.1 -O temp.zip
unzip temp.zip
mv RotorHazard RotorHazard.old
mv RotorHazard-3.1.1 RotorHazard
rm temp.zip
cp RotorHazard.old/src/server/config.json RotorHazard/src/server/
cp RotorHazard.old/src/server/database.db RotorHazard/src/server/
```
The previous installation ends up in the 'RotorHazard.old' directory, which may be deleted or moved.

The minimum version of Python supported is 3.5. If your Python is older than this, you should upgrade using the steps in the Software Setup document under "5. [Install Python](https://github.com/RotorHazard/RotorHazard/blob/main/doc/Software%20Setup.md#5-install-python)."

The RotorHazard server dependencies should also be updated (be patient, this command may take a few minutes):
```
cd ~/RotorHazard/src/server
sudo pip install --upgrade --no-cache-dir -r requirements.txt
```

## RotorHazard Node Code
No updates to the node code have been made since RotorHazard version 3.0.0 (the node-code version is 1.1.4).

## Issues
If you encounter a bug, please report it using the [Issues page on GitHub](https://github.com/RotorHazard/RotorHazard/issues). When reporting issues, using the "Download Logs" button and including the generated '.zip' file is highly recommended (see below).

The Server Log may be displayed via the "View Server Log" item in the drop-down menu. Clicking on the "Select Text" button will select all the displayed log text, which may then be copied and pasted. Clicking on the "Download Logs" button will create and download a '.zip' archive file containing all available log files and the current configuration and database files.

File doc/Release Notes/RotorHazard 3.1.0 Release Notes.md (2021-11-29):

# RotorHazard 3.1.0 Release Notes

## New features and important fixes

### Major refactoring of internal data structures
Cleanup of existing code, including older poorly-written functions. Performance improved by 60% in critical processing areas.

### Improved and expanded public display of information
"Event" page now better describes participants, heat setup, classes, and other event parameters. [Markdown](https://www.markdownguide.org/) may now be used in event and class descriptions for richer, better formatted text when viewed by event participants. Users can define time format strings for better internationalization. Current race and streaming overlays display cached race data when appropriate.

### Expanded LED options
LED panel effects: (lap count, race position, lap time, staging countdown, lap count grid, local RSSI graphing), per-pilot color selection, per-frequency color selection (BetaFlight standard), LED idle states

### Improved user interface
Crossing events now represented in real-time graphs, touch/drag support for setting enter/exit values, new highlight for "late" laps (2nd+ crossing after time expires)

### Improved usability
Recalculate race winner after lap deleted, reversed lap order display option, allow full access is admin fields are empty

Note: Timers using S32_BPill / STM32-based boards should upgrade to this version of RotorHazard, as it fixes an issue ("HTTP Error 406") that occurs when using the 'Update Nodes' feature.

## Detailed updates from RotorHazard 3.0

* Major refactoring of internal data structures #509 #528 #531 #534
* Add Markdown support for event and class descriptions #519
* Display heats by class #521
* Display race starts statistic #522
* Improve and expand public display of Event information #523
* User-defined time formatting #520
* Add graphical crossing indicators #533
* Text effects for LED panels #541
* Local RSSI graph for LED panels #567
* Per-pilot and per-frequency color selection #149 #545
* Add LED idle states #239 #546
* Improve display of "current race" (Current page, stream overlays) with recent race cache
* Improve LED effects and handling #582 #588 
* Enable additional LED effects while using Mirror (Secondary) timers #582
* Save race when requested even if no lap data exists #597
* Save race data on split timer #603
* Improvements to cluster timer reconnects
* Clarify intent with %FREQS% #604
* Fixed issue with adaptive calibration
* Fixed issue with race/pilot reassignments
* Fixed issues with lap source display
* Fixed issue with stream display
* Fixed issue with event results display #599
* Fixed database loading/restore issues #600
* Fixed issue with shutdown LED effects #589
* Show warning if Python 2 version
* Fixed I2C bus issue with RPi 4 and latest OS
* Fixed HTTP Error 406 when updating S32_BPill nodes
* Improved handling S32_BPill board with no modules installed
* Added log of slot positions for S32_BPill rec modules
* Fixed winner not cleared after save/discard
* Volume=zero now fully mutes
* Improve handling gate crossings at race stop #611
* Stop announcing lap numbers after winning laps #612
* Recalculate race winner after lap deleted on Run page #613
* Added 'Lap order reversed' display setting #617
* Added database view command-line args #623
* Allow full access if admin fields are empty
* Various minor fixes and improvements

## Documentation
Documentation for RotorHazard 3.1.0 may be found at:
https://github.com/RotorHazard/RotorHazard/tree/3.1.0/doc

## Installation / Upgrade Notes
To install RotorHazard on a new system, see the instructions in '[doc/Software Setup.md](https://github.com/RotorHazard/RotorHazard/blob/3.1.0/doc/Software%20Setup.md)'

To update an existing RotorHazard installation to this version:
```
cd ~
wget https://codeload.github.com/RotorHazard/RotorHazard/zip/3.1.0 -O temp.zip
unzip temp.zip
mv RotorHazard RotorHazard.old
mv RotorHazard-3.1.0 RotorHazard
rm temp.zip
cp RotorHazard.old/src/server/config.json RotorHazard/src/server/
cp RotorHazard.old/src/server/database.db RotorHazard/src/server/
```
The previous installation ends up in the 'RotorHazard.old' directory, which may be deleted or moved.

The minimum version of Python supported is 3.5. If your Python is older than this, you should upgrade using the steps in the Software Setup document under "5. [Install Python](https://github.com/RotorHazard/RotorHazard/blob/main/doc/Software%20Setup.md#5-install-python)."

The RotorHazard server dependencies should also be updated (be patient, this command may take a few minutes):
```
cd ~/RotorHazard/src/server
sudo pip install --upgrade --no-cache-dir -r requirements.txt
```

## RotorHazard Node Code
No updates to the node code have been made since RotorHazard version 3.0.0 (the node-code version is 1.1.4).

## Issues
If you encounter a bug, please report it using the [Issues page on GitHub](https://github.com/RotorHazard/RotorHazard/issues). When reporting issues, using the "Download Logs" button and including the generated '.zip' file is highly recommended (see below).

The Server Log may be displayed via the "View Server Log" item in the drop-down menu. Clicking on the "Select Text" button will select all the displayed log text, which may then be copied and pasted. Clicking on the "Download Logs" button will create and download a '.zip' archive file containing all available log files and the current configuration and database files.

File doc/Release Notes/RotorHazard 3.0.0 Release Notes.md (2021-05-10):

# RotorHazard 3.0.0 Release Notes

RotorHazard 3.0.0 provides many new features and fixes, including:

### Support for STM32 hardware
A RotorHazard timer can now be built using the new S32_BPill board (with a single STM32 processor instead of multiple Arduinos). This results in significant cost savings and fewer points of failure for new timer builds. RotorHazard maintains compatibility with all existing hardware.

### S32_BPill PCBs and case
See the [resources](https://github.com/RotorHazard/RotorHazard/blob/master/resources/README.md) section for information on the new [S32_BPill board](https://github.com/RotorHazard/RotorHazard/blob/master/resources/S32_BPill_PCB/README.md) and [3D-printable case](https://github.com/RotorHazard/RotorHazard/blob/master/resources/S32_BPill_case/README.md), including extensive documentation and build guides. STM32F1 and STM32F4 chips are supported on "Blue Pill" and "Black Pill" modules. Also check out the compact [RotorHazard 6 Node STM32 board](https://github.com/RotorHazard/RotorHazard/blob/master/resources/6_Node_BPill_PCB/README.md) (contributed by Aaron Smith).

### Data export
Export race data via the Database panel of the Settings page. Exporters are included for CSV and JSON formats with a variety of data types. Export uses a plugin system that will automatically load user-created exporter files for additional flexibility in data and format returned.

### Improved band / channel support
Selecting a frequency now stores the band/channel information instead of just numeric frequency. As a result, the user interface will display the selected band/channel when recalled (previously the first band/channel that matched the same frequency assignment was provided).

### Live graphic tuning
On the tuning dialog, drawing on the graph will immediately update enter and exit values. The "Tuning" button is removed for each node on the `Run` page as clicking on the graph itself opens this dialog.

### UI refresh
The UI has undergone a minor update, including a customized typeface. Disallowed actions no longer appear as UI options. The spacebar functions as a general-purpose hotkey for advancing the event.

### Cluster terminology has changed
A "Master" timer is now known as a "Primary" timer and "Slave" timers are now known as "Secondary" timers. Existing 'SLAVE' keys in the config.json file are still accepted, but their use is deprecated. Please migrate to 'SECONDARY' keys as documented in [Cluster.md](https://github.com/RotorHazard/RotorHazard/blob/3.0.0/doc/Cluster.md).

### End of support for Python 2
Python 2 is past end of life. RotorHazard 3.0 only officially supports Python 3 and some features will no longer function if run with Python 2. [See documentation for upgrade instructions](https://github.com/RotorHazard/RotorHazard/blob/3.0.0/doc/Software%20Setup.md#5-install-python).

## Documentation
Documentation for RotorHazard 3.0.0 may be found at:
https://github.com/RotorHazard/RotorHazard/tree/3.0.0/doc

## Updates from RotorHazard 2.3

* Support for STM32 #482 #483 #538
* Data Export #456 #253
* Store band/channel #492 #499
* Add leader/winner tones #513
* Update relationship terminology #486
* Add support for hardware buzzer and status LED #538 #553
* Update UI for split/mirror connections #472
* Make important server message more prominent in UI #559
* Add space hotkey condition for race save action #564
* Improved database recovery
* Include customized UI typeface
* Removed UI for disallowed actions
* Make i2c bus index configurable #473
* Send peak duration instead of timestamp #432
* Favor best available data when history buffer is full #433
* Reduce i2c chill #409
* Fix Flask_SQLAlchemy dependency incompatibility
* Fix memory leak #527
* Fix issue with exporting unclassified races
* Fix cache issue with failed database load
* Fix file download under Python 3
* Fix filter time compensation #407
* Improve log outputs
* Add warning for split/cluster version mismatch
* Node firmware versioning #518
* Cleanup of language file #488
* Add STM32 build resources #513 #537
* Improve ease of install #555
* Bug fixes and stability improvements #561 #517 #548 #535
* Improve documentation #491 #495 #549 #558 #568
* Update frequency reference with updated Shark Byte assignments #570

## Installation / Upgrade Notes

To install RotorHazard on a new system, see the instructions in '[doc/Software Setup.md](https://github.com/RotorHazard/RotorHazard/blob/3.0.0/doc/Software%20Setup.md)'

To update an existing RotorHazard installation to this version:
```
cd ~
wget https://codeload.github.com/RotorHazard/RotorHazard/zip/3.0.0 -O temp.zip
unzip temp.zip
mv RotorHazard RotorHazard.old
mv RotorHazard-3.0.0 RotorHazard
rm temp.zip
cp RotorHazard.old/src/server/config.json RotorHazard/src/server/
cp RotorHazard.old/src/server/database.db RotorHazard/src/server/
```
The previous installation ends up in the 'RotorHazard.old' directory, which may be deleted or moved.

For RotorHazard the minimum version of Python supported is 3.5. If your Python is older than this, you should upgrade using the steps in the Software Setup document under "5. [Install Python](https://github.com/RotorHazard/RotorHazard/blob/main/doc/Software%20Setup.md#5-install-python)."

The RotorHazard server dependencies should also be updated (be patient, this command may take a few minutes):
```
cd ~/RotorHazard/src/server
sudo pip install --upgrade --no-cache-dir -r requirements.txt
```

## RotorHazard Node Code
New node code is provided with this version. As of this release, the RotorHazard node code supports both [Arduino-based](https://github.com/RotorHazard/RotorHazard/blob/master/src/node/readme_Arduino.md) and [S32_BPill](https://github.com/RotorHazard/RotorHazard/blob/master/resources/S32_BPill_PCB/README.md) boards.

For the S32_BPill board, the recommended method for installing the node firmware is to use the `Update Nodes` button (in the 'System' section on the 'Settings' page) on the RotorHazard web GUI.

Starting with this release the node code is now assigned a version, with this version at "1.1.4". The node-code version may be viewed in the Server Log, and via the "About RotorHazard" item in the drop-down menu.

## Issues
If you encounter a bug, please report it using the [Issues page on GitHub](https://github.com/RotorHazard/RotorHazard/issues). When reporting issues, using the "Download Logs" button and including the generated '.zip' file is highly recommended (see below).

The Server Log may be displayed via the "View Server Log" item in the drop-down menu. Clicking on the "Select Text" button will select all the displayed log text, which may then be copied and pasted. Clicking on the "Download Logs" button will create and download a '.zip' archive file containing all available log files and the current configuration and database files.

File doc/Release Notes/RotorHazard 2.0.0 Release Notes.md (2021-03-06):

# RotorHazard 2.0.0 Release Notes

## Main Features
* Improved node filtering improves timing accuracy and ease of calibration by resisting outlier noise. No longer requires setting filter ratio when changing between indoor and outdoor environments.
* Race history collection: Records signal data during a race so calibration can be adjusted afterward.
* Improved browser timer (system-clock based vs. interval-based): more accurate and better synchronization
* Synchronization and delay compensation for i2c and browser communciations
* Synchronization of LED changes and browser start signals
* Race marshaling: add laps, remove laps, and recalculate all laps based on signal history.
* LiveTime support.
* Race scheduling (delayed staging/start)
* JSON API exposes race data for use by other services on network.
* Supports BME280 temperature sensor and INA219 voltage sensor 

### UI
* Added [keyboard shortcuts](https://github.com/RotorHazard/RotorHazard/blob/main/doc/User%20Guide.md#run) for start race, stop race, save laps, clear laps, manual laps, and dismiss message
* Selectable generated or MP3 tones (each work better on different browsers)
* Improved use of large screen areas
* Warn about suspect calibration values
* Display local race start time
* Display race lap absolute timestamp
* Restore opened panels when results refresh
* Warn about browser timer sync loss
* Less intrusive message location 

### Other
* New 3D printed case design/STL files
* Improved documentation
* Added French language
* Some UK localization
* Optionally used libraries are not required to install
* Simulated interface for developing without hardware present
* Unit tests for important node functions
* Can stop a race during staging
* Bug fixes and performance improvements

## Upgrade Notes
* The monotonic library is now required. Connect the pi to the internet, change to the server directory, then run "sudo pip install -r requirements.txt" to get it.
* Use of [directional RF shielding](https://github.com/RotorHazard/RotorHazard/blob/main/doc/Hardware%20Setup.md#add-a-directional-rf-shield) is now considered a required part of the hardware build.

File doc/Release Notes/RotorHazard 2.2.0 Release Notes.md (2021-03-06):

# RotorHazard 2.2.0 Release Notes

RotorHazard 2.2.0 provides many new features and fixes, including:

### Logging
The RotorHazard interface now has a "View Server Log" menu item (in the "..." menu) and a "Download Logs" button that will create and download a '.zip' archive file containing all available log files and the current configuration and database files. When reporting issues, using the "Download Logs" button and including the generated '.zip' file is highly recommended.

### VRx Control
See doc/Video Receiver.md

### Streaming
The _..._ -> _Stream Displays_ menu option generates a list of URLs which can be directly placed by OBS into scenes.

### Heat Generation
From _Settings_ -> _Heats_ panel. If an input class other than "Randomize" is selected, heats are generated using the "Win Condition" setting of the input class' race format. Lower seeded heats are added first.

### Display Result Source
Mouse over or click/tap on fastest lap or fastest consecutive time to view which round/heat was the source for that time.

## Updates from RotorHazard 2.1.1

* VRx Control and OSD messaging (supports ClearView 2.0) #291 #285 #236 
* Dynamic overlay pages for use with live streaming (OBS) #318 #282 #226
* Improved results generation performance and caching #293 #193 #113
* Heat generation from class results or available pilots #304 #192
* Pilot sorting by name or callsign #297 #195 #177
* Enable removing of unused pilots, heats, classes #300 #8
* Duplicate heats and classes #314 #180
* New options for staging tones #268 #93 #189
* Display source heat/round for result in summary leaderboard #298 #157
* Highlight laps recorded after fixed-time race ends #209 #313
* Arbitrary user text-to-speech callouts #315 #208 #161
* Hardware power saving #311
* Node hardware addressing update #277 #252 
* Enabling in-system programming of nodes #277 #262
* Improved logging and log visibility #330 #324 #289 #283 #295 #301 #303
* Logs saved to file #323
* Automatic log file pruning #323
* Improved database recovery #308
* Internal event system for triggering behaviors; enables plugins and other 3rd party integrations #273 #299
* Fixed pass crossing issues with maxLapsWin races #348
* Node code simplification and cleanup #296
* Node history buffering #230
* Documentation main page #327 
* Experimental node low-pass filter #230
* Code structure improvements #319 #287 #310 
* Database organization improvements #267 #136 
* Bug fixes #312 #305
* Fixed heat generator update on class renaming #332
* Fixed freqs callout wrong frequencies #336
* Fixed IMDtabler reads unused nodes #335
* Added documentation on [logging configuration](https://github.com/RotorHazard/RotorHazard/blob/main/doc/Software%20Setup.md#logging)
* Added Release Notes files in doc
* Other documentation updates

## Upgrade Notes

To install RotorHazard on a new system, see the instructions in doc/Software Setup.md

To update an existing RotorHazard installation to this version:
```
cd ~
wget https://codeload.github.com/RotorHazard/RotorHazard/zip/2.2.0 -O temp.zip
unzip temp.zip
mv RotorHazard RotorHazard.old
mv RotorHazard-2.2.0 RotorHazard
rm temp.zip
cp RotorHazard.old/src/server/config.json RotorHazard/src/server/
cp RotorHazard.old/src/server/database.db RotorHazard/src/server/
```
The previous installation ends up in the 'RotorHazard.old' directory, which may be deleted or moved.

The RotorHazard server dependencies should also be updated (be patient, this command may take a few minutes):
```
cd ~/RotorHazard/src/server
sudo pip install --upgrade --no-cache-dir -r requirements.txt
```

## Node Code (Arduino)
There are node code changes for this version (since 2.1.1) to enable hardware power saving, history buffering, new hardware addressing spec, in-system programming, and other features. Please upgrade using the code supplied with this release.

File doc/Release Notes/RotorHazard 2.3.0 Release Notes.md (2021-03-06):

# RotorHazard 2.3.0 Release Notes

RotorHazard 2.3.0 provides many new features and fixes, including:

### Improved Results Generation
This release provides significant performance advantages when saving races and viewing the results page, particularly for large events. Race results are now atomically cached for each race, heat, class, and event. A local page cache is also maintained. These caching systems are updated on an as-needed basis, preventing rebuild of the entire results cache.

### Expanded Win Conditions and First Crossing Behaviors
Win conditions include common race types and new team racing conditions that use average lap times for the entire team. First crossings can now be hole shots, first lap, or staggered starts. See [Race Formats in the User Guide](https://github.com/RotorHazard/RotorHazard/blob/main/doc/User%20Guide.md#race-format) for more details.

### Retroactive Data Manipulation
Organizers may now remove locks on saved race data to manipulate assigned pilots, heats, classes, etc. for the correction of event setup errors in prior races.

### Database Controls and Migrations
Save, restore, and delete database files in the db_bkp folder from the Database panel in Settings. Also restores database files in older formats.

### Split Timing Improvements
Support for multiple cluster/split timers has been fleshed out and improved. See '[doc/Cluster.md](https://github.com/RotorHazard/RotorHazard/blob/main/doc/Cluster.md)' for details.

### Frequency Reference
A [Frequency Reference](https://github.com/RotorHazard/RotorHazard/blob/main/doc/Frequency%20Reference.md) has been added to documentation, and can be pulled up in the offline documentation viewer.

### Python 3 support
Python 2 is past end of life. RotorHazard 2.3.0 may be run on either Python 2 or Python 3. (This is also the last release to support Python 2; after this release, only Python 3 will be supported.)

### Official PCB release
Paweł Fabiszewski has developed a PCB which implements current hardware standards to simplify wiring and component placement, expediting timer builds and improving usability. See [RotorHazard PCB](https://github.com/RotorHazard/RotorHazard/tree/main/resources/PCB) for more details.

### LiveTime Controls
Visit /decoder to open a dedicated page for settings which apply when RotorHazard is connected to LiveTime.

## Updates from RotorHazard 2.2

* Optimize result page rebuild process #446 
* First crossing options (hole shot, first lap, staggered start) #442
* Retroactive data maniplulation #440
* Added PCB files and documentation #397
* Improved results page build and caching #384
* Added expanded win conditions #339 ([See documentation](https://github.com/RotorHazard/RotorHazard/blob/main/doc/User%20Guide.md#race-format))
* Added "decoder" page for LiveTime settings #316
* Added [Frequency Reference](https://github.com/RotorHazard/RotorHazard/blob/main/doc/Frequency%20Reference.md) to documentation
* Split timer improvements #377 #378 #399 #402 #404 #417 #439
* Python 3 compatibility #320 #415 
* Improved display on iOS #470 
* Automatic dark mode #443
* Reconnect when page regains visibility (device wakes from sleep) #447
* Server support of up to 16 nodes (I2C limit is still 8)
* Fix major issue with events and multiple assigned handlers
* Restore and delete databases from UI #59 #421
* Added DJI 50MB channels as "J" band
* Updated DJI 25MB Ch6 to 5880
* Added Shark Byte channels as "S" band
* Added start-of-race enter/exit lowering #389
* Made auto heat increment optional #394
* Added hotkey for start/stop race (spacebar) #437 
* Added more announcement options #395
* Support most recent CVCM protocol #408
* Allow log updates page to be paused #401 #422
* Improved database migrations and fix issues #415
* Enforce format switch on heat change and race staging
* Added semaphore lock for node I/O access #467
* Clears stream node display when seat is empty
* Handle system clock time jumps #439
* Improve message queuing for cluster timers #455
* VRx Control shuts off OSD on CV2.0 #457
* VRx Control uses preliminary JSON protocol #438
* Remove 'null' pilots from results list #388
* Add folder for user data that is not overwritten on update #356 #423
* Ensure correct permissions on generated files and folders
* Improved exception catching/logging on thread/route/render functions #387
* Decoupled sensors from timing interface #386 
* Improved translation support #414 #425
* Additional German translations #414 #425
* Fixed scheduled race cancellation
* Fixed plugin loading #373
* Code refactoring #398 
* Alter last heat's ID to 1 after others deleted #426
* Various minor bug fixes and improvements
* Improved documentation #403

## Upgrade Notes

To install RotorHazard on a new system, see the instructions in '[doc/Software Setup.md](https://github.com/RotorHazard/RotorHazard/blob/main/doc/Software%20Setup.md)'

To update an existing RotorHazard installation to this version:
```
cd ~
wget https://codeload.github.com/RotorHazard/RotorHazard/zip/2.3.0 -O temp.zip
unzip temp.zip
mv RotorHazard RotorHazard.old
mv RotorHazard-2.3.0 RotorHazard
rm temp.zip
cp RotorHazard.old/src/server/config.json RotorHazard/src/server/
cp RotorHazard.old/src/server/database.db RotorHazard/src/server/
```
The previous installation ends up in the 'RotorHazard.old' directory, which may be deleted or moved.

The RotorHazard server dependencies should also be updated (be patient, this command may take a few minutes):
```
cd ~/RotorHazard/src/server
sudo pip install --upgrade --no-cache-dir -r requirements.txt
```

## Node Code (Arduino)
There are no node code changes for this version since 2.2.0. You will need to upgrade your Arduino firmware only if upgrading from a version prior to 2.2.

## Issues
If you encounter a bug, please report it using the [Issues page on GitHub](https://github.com/RotorHazard/RotorHazard/issues). Open "View Server Log" (in the "..." menu) and a "Download Logs" button will create and download a '.zip' archive file containing all available log files and the current configuration and database files.

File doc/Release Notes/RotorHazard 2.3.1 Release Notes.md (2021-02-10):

# RotorHazard 2.3.1 Release Notes

## Updates from 2.3.0

 * Fix LiveTime Decoder page
 * Fix Java detection for Python 3.8 #477
 * Resolve deprecated log functions #476

See [release notes from 2.3.0](https://github.com/RotorHazard/RotorHazard/releases/tag/2.3.0) for more information on this version.

## Documentation

Documentation for RotorHazard 2.3.1 may be found at:
https://github.com/RotorHazard/RotorHazard/blob/2.3.1/doc/README.md

## Installation / Upgrade Notes

To install RotorHazard on a new system, see the instructions in [doc/Software Setup.md](https://github.com/RotorHazard/RotorHazard/blob/2.3.1/doc/Software%20Setup.md)

To update an existing RotorHazard installation to this version:
```
cd ~
wget https://codeload.github.com/RotorHazard/RotorHazard/zip/2.3.1 -O temp.zip
unzip temp.zip
mv RotorHazard RotorHazard.old
mv RotorHazard-2.3.1 RotorHazard
rm temp.zip
cp RotorHazard.old/src/server/config.json RotorHazard/src/server/
cp RotorHazard.old/src/server/database.db RotorHazard/src/server/
```
The previous installation ends up in the 'RotorHazard.old' directory, which may be deleted or moved.

The RotorHazard server dependencies should also be updated (be patient, this command may take a few minutes):
```
cd ~/RotorHazard/src/server
sudo pip install --upgrade --no-cache-dir -r requirements.txt
```

## Node Code (Arduino)
There are no node code changes for this version since 2.2.0. You will need to upgrade your Arduino firmware only if upgrading from a version prior to 2.2.

## Issues
If you encounter a bug, please report it using the [Issues page on GitHub](https://github.com/RotorHazard/RotorHazard/issues). Open "View Server Log" (in the "..." menu) and a "Download Logs" button will create and download a '.zip' archive file containing all available log files and the current configuration and database files.

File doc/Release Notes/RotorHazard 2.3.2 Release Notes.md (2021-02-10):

# RotorHazard 2.3.2 Release Notes

## Updates from 2.3.1

 * Improved compatibility with hardware and python version differences
 * Realign documentation with other updates

See [release notes from 2.3.0](https://github.com/RotorHazard/RotorHazard/releases/tag/2.3.0) and [release notes from 2.3.1](https://github.com/RotorHazard/RotorHazard/releases/tag/2.3.1) for more information on this version.

## Documentation

Documentation for RotorHazard 2.3.2 may be found at:
https://github.com/RotorHazard/RotorHazard/blob/2.3.2/doc/README.md

## Installation / Upgrade Notes

To install RotorHazard on a new system, see the instructions in [doc/Software Setup.md](https://github.com/RotorHazard/RotorHazard/blob/2.3.2/doc/Software%20Setup.md)

Use the commands below to update an existing RotorHazard installation to this version. (Before updating, any currently-running RotorHazard server should be [stopped](https://github.com/RotorHazard/RotorHazard/blob/2.3.2/doc/Software%20Setup.md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).)
```
cd ~
wget https://codeload.github.com/RotorHazard/RotorHazard/zip/2.3.2 -O temp.zip
unzip temp.zip
mv RotorHazard RotorHazard.old
mv RotorHazard-2.3.2 RotorHazard
rm temp.zip
cp RotorHazard.old/src/server/config.json RotorHazard/src/server/
cp RotorHazard.old/src/server/database.db RotorHazard/src/server/
```
The previous installation ends up in the 'RotorHazard.old' directory, which may be deleted or moved.

The RotorHazard server dependencies should also be updated (be patient, this command may take a few minutes):
```
cd ~/RotorHazard/src/server
sudo pip install --upgrade --no-cache-dir -r requirements.txt
```

## Node Code (Arduino)
There are no node code changes for this version since 2.2.0. You will need to upgrade your Arduino firmware only if upgrading from a version prior to 2.2.

## Issues
If you encounter a bug, please report it using the [Issues page on GitHub](https://github.com/RotorHazard/RotorHazard/issues). Open "View Server Log" (in the "..." menu) and a "Download Logs" button will create and download a '.zip' archive file containing all available log files and the current configuration and database files.

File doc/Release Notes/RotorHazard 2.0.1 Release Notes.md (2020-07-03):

# RotorHazard 2.0.1 Release Notes

## Updates
* Language translation updates
* Update LED library
* Fix LEDs not actually optional
* Fix opening Marshal page clears local settings
* Fix database recovery of RSSI thresholds
* Update requirements to prevent dependency vulnerabilities
* Add DJI channels

## Upgrade Notes
* If you run LEDs, you will need to update the rpi_281x library. Connect the pi to the internet, then run "sudo pip install --upgrade rpi_ws281x".

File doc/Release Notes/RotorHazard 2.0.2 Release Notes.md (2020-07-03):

# RotorHazard 2.0.2 Release Notes

## Updates
* Improve CORS handling (fixes LiveTime support)
* Set dependency requirements to known working versions
* Improve LED detection (support older lib)
* Language updates
* Minor cleanup

## Upgrade Notes
* After updating project files, change to ~/RotorHazard/src/server and run "sudo pip install --upgrade -r requirements.txt" to update dependencies to known working versions. This can take a few minutes to run. This is not required for new builds.

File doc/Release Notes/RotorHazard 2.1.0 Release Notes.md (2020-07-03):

# RotorHazard 2.1.0 Release Notes

## Updates from 2.0

 * Improved browser/pi time sync (improves sync of audio/LED start signals and time capture)
 * Adjust calibration based on pilot/node history
 * Touch-marshaling: click and drag on graph to quickly select laps and adjust tuning parameters
 * Auto-increment heat when race is saved (maintains same class)
 * LED effects library
 * LED management maps effects to timer events
 * LED panel support: image bitmap display, image rotation, row index conversion
 * Colorblind- and FPV-camera-friendly images for 16x16 LED panels
 * Improved responsiveness (non-blocking pass callbacks and results calculations)
 * Improved documentation; especially tuning parameters with new illustrations
 * Offline documentation reader
 * Improved UI for race marshaling (graph scaling, data reload, default to most recently run race)
 * New heat pilot assignments default to "None"
 * Hide disabled nodes from UI (when disabled by frequency)
 * Keep deleted realtime laps for restoration in marshaling
 * Frontend display of lap number, time since start, time since lap 0 (Klaus-Michael PR #105)
 * Highlight laps recorded after time has expired during a fixed-time race
 * Generic sensor framework (pulquero PR #159)
 * Support for USB-connected nodes (see 'doc/USB Nodes.md')
 * Cleaned-up and improved node code (pulquero PR #99)
 * Added node I2C comms monitor (should prevent unresponsive nodes)
 * Improved node status LED: now shows idle (2s blink), crossing (solid), and data bus activity
 * Split-timing support (experimental) (pulquero PR #94)
 * Band scanner (experimental, enabled via Debug config flag) (pulquero)
 * Browser sync quality now visible under ... -> About RotorHazard (Run or Current page only)
 * Added server reboot button
 * Various bug fixes and minor improvements
 * Added primary documentation translations (es, pl)
 * Added Polish language
 * Language updates
 * Dependency updates

### LED Panel

LED panel hardware is configured exactly like LED strips. To enable image display, follow the instructions at the top of src/server/led_handler_bitmap.py to install necessary libraries. See config-dist.json for new LED options that may be used. If your panel image requires rotation, use `PANEL_ROTATE` with the number of 90-degree CCW rotations needed [0..3]. Some panels are not wired in a typical left-to-right pattern and are instead wired in a Z-pattern (every other row is addressed right-to-left). Set `"INVERTED_PANEL_ROWS": true` to correct this.

### Upgrade Notes

To install RotorHazard on a new system, see the instructions in doc/Software Setup.md

To update an existing RotorHazard installation to this version:
```
cd ~
wget https://codeload.github.com/RotorHazard/RotorHazard/zip/2.1.0 -O temp.zip
unzip temp.zip
mv RotorHazard RotorHazard.old
mv RotorHazard-2.1.0 RotorHazard
rm temp.zip
cp RotorHazard.old/src/server/config.json RotorHazard/src/server/
cp RotorHazard.old/src/server/database.db RotorHazard/src/server/
```
The previous installation ends up in the 'RotorHazard.old' directory, which may be deleted or moved.

The RotorHazard server dependencies should also be updated (be patient, this command may take a few minutes):
```
cd ~/RotorHazard/src/server
sudo pip install --upgrade --no-cache-dir -r requirements.txt
```

### Node Code (Arduino)

Node code changes for NODE_API_LEVEL 22 provide faster node polling and more robust operation (with recovery via a communications monitor). Please upgrade using the code supplied with this release. This version is not different from 2.1.0-beta.2, no updates are needed if upgrading from that version or later.

As always, to report bugs please post a GitHub issue [here](https://github.com/RotorHazard/RotorHazard/issues).

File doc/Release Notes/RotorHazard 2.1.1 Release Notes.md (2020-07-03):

# RotorHazard 2.1.1 Release Notes

## Updates from 2.1.0

 * Fix LED custom color selector
 * Fix profile selector
 * Added support for RGBW strips
 * Improved documentation and translations

See [release notes from 2.1.0](https://github.com/RotorHazard/RotorHazard/releases/tag/2.1.0) for more information on this version.

## Upgrade Notes

To install RotorHazard on a new system, see the instructions in doc/Software Setup.md

To update an existing RotorHazard installation to this version:
```
cd ~
wget https://codeload.github.com/RotorHazard/RotorHazard/zip/2.1.1 -O temp.zip
unzip temp.zip
mv RotorHazard RotorHazard.old
mv RotorHazard-2.1.1 RotorHazard
rm temp.zip
cp RotorHazard.old/src/server/config.json RotorHazard/src/server/
cp RotorHazard.old/src/server/database.db RotorHazard/src/server/
```
The previous installation ends up in the 'RotorHazard.old' directory, which may be deleted or moved.

The RotorHazard server dependencies should also be updated (be patient, this command may take a few minutes):
```
cd ~/RotorHazard/src/server
sudo pip install --upgrade --no-cache-dir -r requirements.txt
```

## Node Code (Arduino)

No additional code changes have been made to nodes since the 2.1.0 release.

As always, to report bugs please post a [GitHub issue](https://github.com/RotorHazard/RotorHazard/issues).

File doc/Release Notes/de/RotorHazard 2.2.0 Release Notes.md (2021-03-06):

# Versionshinweise zu RotorHazard 2.2.0

RotorHazard 2.2.0 bietet viele neue Funktionen und Korrekturen, darunter:

### Protokollierung

Die RotorHazard-Oberfläche verfügt jetzt über einen Menüpunkt "Serverprotokoll anzeigen" (im Menü "...") und eine Schaltfläche "Protokolle herunterladen", mit der eine ".zip" -Archivdatei erstellt und heruntergeladen wird, die alle verfügbaren Protokoll-, die aktuellen Konfigurations- und Datenbankdateien. Wenn Sie Probleme melden, wird dringend empfohlen, die Schaltfläche "Protokolle herunterladen" zu verwenden und die generierte ZIP-Datei einzuschließen.

### VRx-Steuerung

Siehe [doc/Video Receiver.md](doc/de-Video%20Receiver.md)

### Streaming

Die Menüoption _..._-> _Stream Displays_ generiert eine Liste von URLs, die von OBS direkt in Szenen eingefügt werden können.

### Erzeugung von Läufen

Aus dem Bereich _Einstellungen_ -> _Läufe_. Wenn eine andere Eingabeklasse als "Zufällig" ausgewählt ist, werden Vorläufe mit der Einstellung "Gewinnbedingung" des Rennformats der Eingabeklasse generiert. Niedrigere Läufe werden zuerst hinzugefügt.

### Ergebnisquelle anzeigen

Fahren Sie mit der Maus über oder klicken / tippen Sie auf die schnellste Runde oder die schnellste aufeinanderfolgende Zeit, um zu sehen, welche Runde / Hitze die Grundlage für diese Zeit war.

## Updates von RotorHazard 2.1.1

* VRx Control und OSD-Messaging (unterstützt ClearView 2.0) #291 #285 #236
* Dynamische Overlay-Seiten zur Verwendung mit Live-Streaming (OBS) #318 #282 #226
* Verbesserte Leistung bei der Ergebnisgenerierung und Zwischenspeicherung #293 #193 #113
* Erzeugung von Läufen aus Klassenergebnissen oder verfügbaren Piloten #304 #192
* Sortierung der Piloten nach Name oder Rufzeichen #297 #195 #177
* Aktivieren von "Entfernen nicht verwendeter Piloten, Vorläufe, Klassen" #300 #8
* Duplizierung von Vorläufen und Klassen #314 #180
* Neue Optionen für die Inszenierung von Tönen #268 #93 #189
* Anzeige der Läufe / Runden für das Ergebnis in der zusammenfassenden Bestenliste #298 #157
* Markieren Sie Runden, die nach dem Ende des Rennens mit fester Zeit aufgezeichnet wurden #209 #313
* Beliebige Benutzer-Text-zu-Sprache-Beschriftungen #315 #208 #161
* Hardware-Energieeinsparung #311
* Update der Knotenhardwareadressierung #277 #252
* Aktivieren der systeminternen Programmierung von Knoten #277 #262
* Verbesserte Protokollierung und Protokollsichtbarkeit #330 #324 #289 #283 #295 #301 #303
* In Datei #323 gespeicherte Protokolle
* Automatisches Bereinigen von Protokolldateien #323
* Verbesserte Datenbankwiederherstellung #308
* Internes Ereignissystem zum Auslösen von Verhalten; aktiviert Plugins und andere Integrationen von Drittanbietern #273 #299
* Probleme beim Überqueren von Pässen bei maxLapsWin-Rennen #348 wurden behoben
* Vereinfachung und Bereinigung des Knotencodes #296
* Knotenverlaufspufferung #230
* Hauptseite der Dokumentation #327
* Experimenteller Knoten-Tiefpassfilter #230
* Verbesserungen der Codestruktur #319 #287 #310
* Verbesserungen der Datenbankorganisation #267 #136
* Fehlerbehebungen #312 #305
* Das Update des Wärmeerzeugers beim Umbenennen der Klasse #332 wurde behoben
* Fehler behoben: Freqs Callout falsche Frequenzen #336
* Behoben, dass IMDtabler nicht verwendete Knoten #335 liest
* Dokumentation zu [Protokollierungskonfiguration](https://github.com/RotorHazard/RotorHazard/blob/main/doc/de-Software%20Setup.md#logging) hinzugefügt
* Versionshinweisdateien im Dokument hinzugefügt
* Andere Dokumentationsaktualisierungen

## Upgrade-Hinweise

Informationen zum Installieren von RotorHazard auf einem neuen System finden Sie in den Anweisungen in doc / Software Setup.md

So aktualisieren Sie eine vorhandene RotorHazard-Installation auf diese Version:

```
cd ~
wget https://codeload.github.com/RotorHazard/RotorHazard/zip/2.2.0 -O temp.zip
unzip temp.zip
mv RotorHazard RotorHazard.old
mv RotorHazard-2.2.0 RotorHazard
rm temp.zip
cp RotorHazard.old/src/server/config.json RotorHazard/src/server/
cp RotorHazard.old/src/server/database.db RotorHazard/src/server/
```

Die vorherige Installation landet im Verzeichnis 'RotorHazard.old', das gelöscht oder verschoben werden kann.

Die RotorHazard-Serverabhängigkeiten sollten ebenfalls aktualisiert werden (haben Sie etwas Geduld, dieser Befehl kann einige Minuten dauern):

```
cd ~/RotorHazard/src/server
sudo pip install --upgrade --no-cache-dir -r requirements.txt
```

## Knotencode (Arduino)

Für diese Version (seit 2.1.1) wurden Änderungen am Knotencode vorgenommen, um Hardware-Energieeinsparung, Verlaufspufferung, neue Hardware-Adressierungsspezifikation, systeminterne Programmierung und andere Funktionen zu ermöglichen. Bitte aktualisieren Sie diese mit dem in dieser Version enthaltenen Code.

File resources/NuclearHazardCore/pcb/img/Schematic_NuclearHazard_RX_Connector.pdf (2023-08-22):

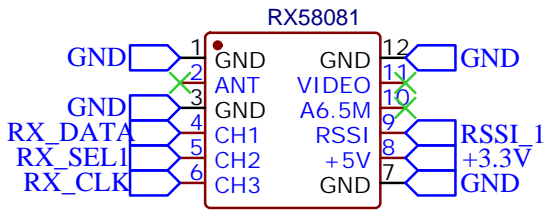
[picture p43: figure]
GND 1 ANT 2 GND 3 CH1 4 CH2 5; GND 7; RSSI 9; A6.5M 10 VIDEO 11 GND 12; GND; RX_DATA; RX_CLK; RX_SEL1; RSSI_1
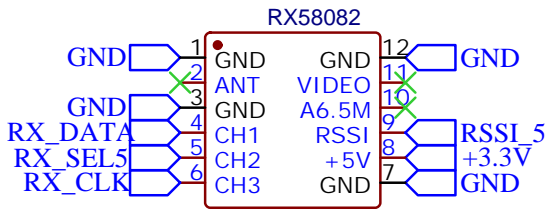
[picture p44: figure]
GND; GND 1 ANT 2 GND 3 CH1 4 CH2 5; GND 7; RSSI 9; A6.5M 10 VIDEO 11 GND 12; RX_DATA; RX_CLK; RX_SEL5; RSSI_5
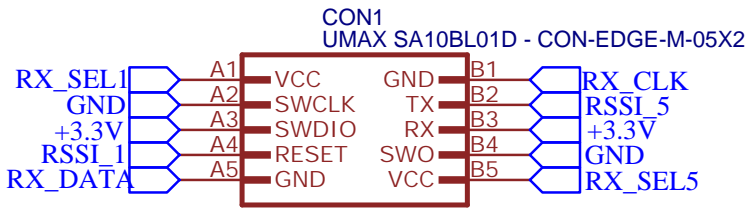
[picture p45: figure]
UMAX SA10BL01D - CON-EDGE-M-05X2; CON1; VCC A1 SWCLK A2 SWDIO A3 RESET A4; GND A5; VCC; B5 SWO; B2 GND; +3.3V RSSI_1; RX_SEL1 GND; RX_SEL5; RSSI_5 +3.3V GND; RX_CLK; RX_DATA

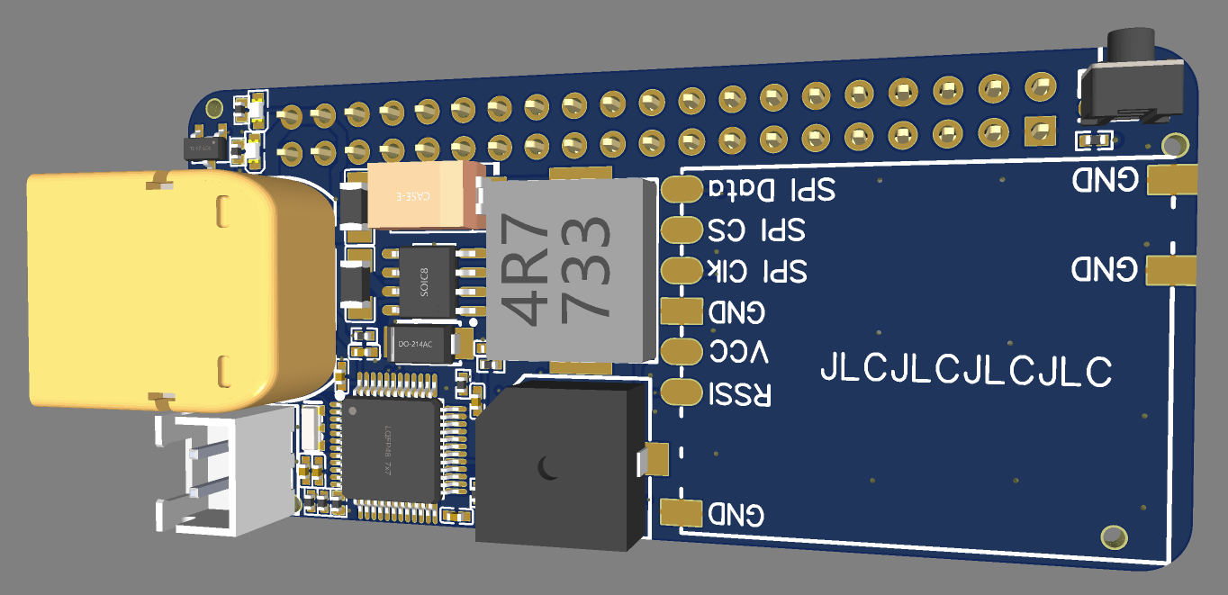
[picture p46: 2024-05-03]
resources/NuclearHazardAtom/img/Atom 3D.png

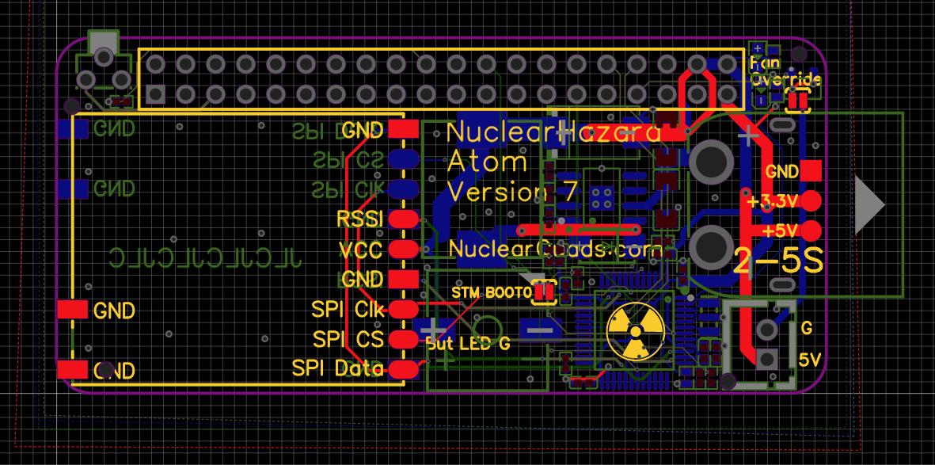
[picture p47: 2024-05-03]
resources/NuclearHazardAtom/img/Atom Layout.png

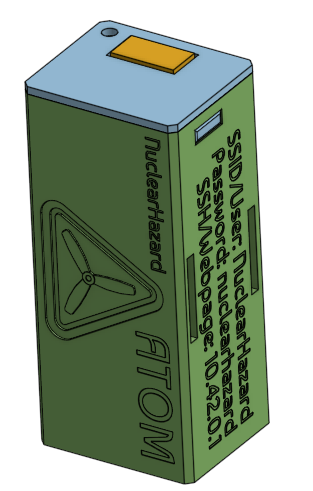
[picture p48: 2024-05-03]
resources/NuclearHazardAtom/img/Atom Case.png

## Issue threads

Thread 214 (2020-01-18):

RACE DID NOT START after panel setup and trying to start a race.

BoLtWD, 2020-01-18:
Ref MASTER download issue found downloaded on Jan 18, 2020

I know this is in BETA, I have been testing the installation of an LED panel, I don`t have the panel yet and just using LEDs I have for now and just setting up the code.

1. As commented by Michael  I first installed  cv2; using sudo apt-get install python-opencv

2. Then, copy the config info from the top of bitmap_led_handler.py into my LED section of the config file WITHOUT THE COMMA AFTER led count number.

3. Ran the timer and logged in

The LEDs did not indicate as LED strip dose on start up.
Tested LEDs in LED section by activating buttons and inspecting corresponding for colors, ALL OK
Running a race, Activated START, RACE DID NOT START AND NO LEDS, could not repress start so refreshed page only to see the start button return to normal (not grayed out) . Repeated pressing start to get same result.

This may be something to do with my setup above or an issue.

Shot in the dark, could this be down to this needing installing?     import numpy as np   found in bitmap_led_handler.py  line 28 ?

Hope my testing helps.

HazardCreative, 2020-01-19:
Run your timer from the console and see if there are any errors.

BoLtWD, 2020-01-19:
There is an error **KeyError: 'PANEL_ROTATE'**  See below

pi@RACE_TIMER:~/RotorHazard/src/server $ python server.py

Configuration file imported
Loaded module i2c_helper
Loaded module i2c_node
Loaded module serial_node
I2C node 1 found at address 8
I2C node 2 found at address 10
I2C node 3 found at address 12
I2C node 4 found at address 14
I2C node 5 found at address 16
I2C node 6 found at address 18
I2C node 7 found at address 20
I2C node 8 found at address 22
Node 1: API_level=21, Freq=5658, EnterAt=99, ExitAt=88
Node 2: API_level=21, Freq=5695, EnterAt=94, ExitAt=84
Node 3: API_level=21, Freq=5760, EnterAt=81, ExitAt=70
Node 4: API_level=21, Freq=5800, EnterAt=94, ExitAt=84
Node 5: API_level=21, Freq=5917, EnterAt=60, ExitAt=49
Node 6: API_level=21, Freq=5800, EnterAt=86, ExitAt=76
Node 7: API_level=21, Freq=5800, EnterAt=85, ExitAt=75
Node 8: API_level=21, Freq=5800, EnterAt=60, ExitAt=51
Loaded module bme280_sensor
Loaded module ina219_sensor
Loaded module pi_sensor
BME280 found at address 118
No BME280 at address 119
INA219 found at address 64
No INA219 at address 65
No INA219 at address 68
No INA219 at address 69
Program started at 1579450042221.000000
Language file imported
Number of nodes found: 8
Release: 2.1.0 (dev 3) / Server API: 25 / Latest Node API: 21
Found installed:  java version "1.8.0_65"
Found installed:  IMDTabler Version 1.3
Database current laps reset
Set Profile to '3'
LED: selecting library "rpi_ws2812x"
LED: hardware GPIO enabled, count=256, pin=10, freqHz=800000, dma=10, invert=False, chan=0, strip=GRB/528384
Running http server at port 5000
Client connected
Heartbeat thread started
Interface: Starting background thread.
Client disconnected
Client connected
set race format to 'Open Practice' (5)
Traceback (most recent call last):
  File "src/gevent/greenlet.py", line 766, in gevent._greenlet.Greenlet.run
  File "/usr/local/lib/python2.7/dist-packages/socketio/server.py", line 648, in _handle_event_internal
    r = server._trigger_event(data[0], namespace, sid, *data[1:])
  File "/usr/local/lib/python2.7/dist-packages/socketio/server.py", line 677, in _trigger_event
    return self.handlers[namespace][event](*args)
  File "/usr/local/lib/python2.7/dist-packages/flask_socketio/__init__.py", line 284, in _handler
    *args)
  File "/usr/local/lib/python2.7/dist-packages/flask_socketio/__init__.py", line 698, in _handle_event
    ret = handler(*args)
  File "server.py", line 1709, in on_stage_race
    led_handler.staging()
  File "/home/pi/RotorHazard/src/server/bitmap_led_handler.py", line 43, in render
    rotated = np.rot90(img, self.config['PANEL_ROTATE'])
KeyError: 'PANEL_ROTATE'
2020-01-19T16:08:11Z <Thread at 0x6c6af718: <bound method Server._handle_event_internal of <socketio.server.Server object at 0x7536c930>>(<socketio.server.Server object at 0x7536c930>, '23fb9b521c2748ee806d3292c3ed1ca1', [u'stage_race'], '/', None)> failed with KeyError

Client disconnected
Client connected
set race format to 'Open Practice' (5)

BoLtWD, 2020-01-19:
This is my config.json

{
	"GENERAL": {
		"HTTP_PORT": 5000,
		"SECRET_KEY": "secret!",
		"ADMIN_USERNAME": "admin",
		"ADMIN_PASSWORD": "thiswayup",
		"DEBUG": false,
		"CORS_ALLOWED_HOSTS": "*"
	},
	"SENSORS": {},
	"SERIAL_PORTS": [],
	"LED": {
		"HANDLER": "bitmap",
		"BITMAPS": {
			"staging": [{
				"image": "static/image/LEDpanel-status-staging.png",
				"delay": 0
			}],
			"start": [{
				"image": "static/image/LEDpanel-status-start.png",
				"delay": 0
			}],
			"stop": [{
				"image": "static/image/LEDpanel-status-stop.png",
				"delay": 0
			}],
			"finished": [{
				"image": "static/image/LEDpanel-status-finished.png",
				"delay": 0
			}]
		},
		"LED_COUNT": 256
	}
}

HazardCreative, 2020-01-19:
Thanks! Definitely a bug, but there's an easy fix.
As a workaround, you can add a PANEL_ROTATE key to your config within BITMAPS. Set it to 0 to start with.

BoLtWD, 2020-01-19:
I think I did what you asked but in the GUI same issue, no problem as at least you know about it please see below to what I have done. I will revert my config to the standard so all will work as normal until fix. Let me know If I can test any fixes for you.

**config.json**

{
	"GENERAL": {
		"HTTP_PORT": 5000,
		"SECRET_KEY": "secret!",
		"ADMIN_USERNAME": "admin",
		"ADMIN_PASSWORD": "landed",
		"DEBUG": false,
		"CORS_ALLOWED_HOSTS": "*"
	},
	"SENSORS": {},
	"SERIAL_PORTS": [],
	"LED": {
		"HANDLER": "bitmap",
		"BITMAPS": {
			"staging": [{
				"image": "static/image/LEDpanel-status-staging.png",
				"delay": 0
			}],
			"start": [{
				"image": "static/image/LEDpanel-status-start.png",
				"delay": 0
			}],
			"stop": [{
				"image": "static/image/LEDpanel-status-stop.png",
				"delay": 0
			}],
			"finished": [{
				"image": "static/image/LEDpanel-status-finished.png",
				"delay": 0
			}]
		},
		"LED_COUNT": 256,
		"PANEL_ROTATE": 0
	}
}

**Console**

pi@RACE_TIMER:~/RotorHazard/src/server $ python server.py
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
HazardCreative, 2020-01-19:
I think you pasted the wrong log, but it looks like "INVERTED_PANEL_ROWS": false, is not optional yet as well. Put it after PANEL_ROTATE. But I should have a patch for this shortly.

BoLtWD, 2020-01-19:
**config.json**

{
	"GENERAL": {
		"HTTP_PORT": 5000,
		"SECRET_KEY": "secret!",
		"ADMIN_USERNAME": "admin",
		"ADMIN_PASSWORD": "ilandintrees",
		"DEBUG": false,
		"CORS_ALLOWED_HOSTS": "*"
	},
	"SENSORS": {},
	"SERIAL_PORTS": [],
	"LED": {
		"HANDLER": "bitmap",
		"INVERTED_PANEL_ROWS": false,
		"BITMAPS": {
				"PANEL_ROTATE": 0,
			"staging": [{
				"image": "static/image/LEDpanel-status-staging.png",
				"delay": 0
			}],
			"start": [{
				"image": "static/image/LEDpanel-status-start.png",
				"delay": 0
			}],
			"stop": [{
				"image": "static/image/LEDpanel-status-stop.png",
				"delay": 0
			}],
			"finished": [{
				"image": "static/image/LEDpanel-status-finished.png",
				"delay": 0
			}]
		          },
		"LED_COUNT": 256

	}
}

**Console**

pi@RACE_TIMER:~/RotorHazard/src/server $ python server.py
Configuration file imported
Loaded module i2c_helper
Loaded module i2c_node
Loaded module serial_node
I2C node 1 found at address 8
I2C node 2 found at address 10
I2C node 3 found at address 12
I2C node 4 found at address 14
I2C node 5 found at address 16
I2C node 6 found at address 18
I2C node 7 found at address 20
I2C node 8 found at address 22
Node 1: API_level=21, Freq=5658, EnterAt=99, ExitAt=88
Node 2: API_level=21, Freq=5695, EnterAt=94, ExitAt=84
Node 3: API_level=21, Freq=5760, EnterAt=81, ExitAt=70
Node 4: API_level=21, Freq=5800, EnterAt=94, ExitAt=84
Node 5: API_level=21, Freq=5917, EnterAt=60, ExitAt=49
Node 6: API_level=21, Freq=5800, EnterAt=86, ExitAt=76
Node 7: API_level=21, Freq=5800, EnterAt=85, ExitAt=75
Node 8: API_level=21, Freq=5800, EnterAt=60, ExitAt=51
Loaded module bme280_sensor
Loaded module ina219_sensor
Loaded module pi_sensor
BME280 found at address 118
No BME280 at address 119
INA219 found at address 64
No INA219 at address 65
No INA219 at address 68
No INA219 at address 69
Program started at 1579461637428.000000
Language file imported
Number of nodes found: 8
Release: 2.1.0 (dev 3) / Server API: 25 / Latest Node API: 21
Found installed:  java version "1.8.0_65"
Found installed:  IMDTabler Version 1.3
Database current laps reset
Set Profile to '3'
LED: selecting library "rpi_ws2812x"
LED: hardware GPIO enabled, count=256, pin=10, freqHz=800000, dma=10, invert=False, chan=0, strip=GRB/528384
Running http server at port 5000
Client connected
Heartbeat thread started
Interface: Starting background thread.
Client disconnected
Client connected
set race format to 'Open Practice' (5)
Traceback (most recent call last):
  File "src/gevent/greenlet.py", line 766, in gevent._greenlet.Greenlet.run
  File "/usr/local/lib/python2.7/dist-packages/socketio/server.py", line 648, in _handle_event_internal
    r = server._trigger_event(data[0], namespace, sid, *data[1:])
  File "/usr/local/lib/python2.7/dist-packages/socketio/server.py", line 677, in _trigger_event
    return self.handlers[namespace][event](*args)
  File "/usr/local/lib/python2.7/dist-packages/flask_socketio/__init__.py", line 284, in _handler
    *args)
  File "/usr/local/lib/python2.7/dist-packages/flask_socketio/__init__.py", line 698, in _handle_event
    ret = handler(*args)
  File "server.py", line 1709, in on_stage_race
    led_handler.staging()
  File "/home/pi/RotorHazard/src/server/bitmap_led_handler.py", line 45, in render
    self.setPixels(rotated)
  File "/home/pi/RotorHazard/src/server/bitmap_led_handler.py", line 58, in setPixels
    if self.config['INVERTED_PANEL_ROWS']:
KeyError: 'INVERTED_PANEL_ROWS'
2020-01-19T19:21:20Z <Thread at 0x6c7877a0: <bound method Server._handle_event_internal of <socketio.server.Server object at 0x75341930>>(<socketio.server.Server object at 0x75341930>, '93d4bb4fd4e745aeb9bac1bb800f2dbb', [u'stage_race'], '/', None)> failed with KeyError

BoLtWD, 2020-01-19:
Not expecting a fix just testing anything you want me to, hopefully to help

HazardCreative, 2020-01-19:
INVERTED_PANEL_ROWS goes within BITMAPS as well. But it shouldn't be necessary anymore, and neither should PANEL_ROTATE... or any of the rest of the BITMAPS section unless you want to change the defaults.

BoLtWD, 2020-01-19:
Sorry not having a good night, at least you have a fix. Nice work

Closed 2020-01-19.

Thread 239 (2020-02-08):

After Save/Discard laps option to have leds default to a preselected state

BoLtWD, 2020-02-08:
After Save/Discard laps is it possible to have an option to have leds default to a preselected state saved in settings, example RotorHazard logo or image or color pattern.

HazardCreative, 2020-02-08:
The 'save race' button actually runs the code for both 'save' and 'discard' so it's not a drop-in addition of an event. (Thought it shouldn't be a big deal to split them.) However, I'd like to know what other timer events the community is interested in having LED effects for.

BoLtWD, 2020-02-08:
I don't think I am explaining correctly. At this time when you select save or discard the led panel or led strip turns off and nothing is displayed without manual intervention. Just wondering if it's possible to have leds default to a preselected state saved in settings, example RotorHazard logo or image or color pattern or nothing (off). This is the same for when the server is running and finished displaying STARTUP leds, the pannel goes off.

Again sorry if I am not explaning correctly.

I like the idea of a panel or strip on the bases it could help hard of hearing pilots and act as a visual aid to all.

As for events Tiny Whoops are fantastic in winter times and leds for these are a must,  due to the crappy cameras on them the images like the pause is unclear. I have been playing with a  orange standby symbol and this is a bit more defined for the low quality cameras.
There is starting to be a big push by Jesse P to get Tiny Whoop more into the uk.

HazardCreative, 2020-02-08:
No, I get what you're asking and it makes sense. I think you've just misunderstood the terminology. Here, an event is an action or system state. An effect is any LED change. Here, the "event" would be "Save Laps" or "Discard Laps". The currently applied "effect" is "Turn Off".

The system is still in active development. If there are other events where an effect is desired I'd like to understand what they are.

As an aside, though connected services are possible, RotorHazard will *never* require an active internet connection to use. I have a strong opinion about that. I'm interested in your experiments on the specifics of the staging signal. You already know I am going to be fairly particular about it, but I'm not 100% sold on the current option. But that's a topic for another issue.

BoLtWD, 2020-02-08:
For me I believe you have covered all the events needed as all other would be outside of the timer and race operations. The only thing I can think of would be some indication of change of heats example below (I will leave the real look up to your wisdom). This could be the image when you select save or discard that is defaults to and when you change a heat the number and possibly color of the number changes for each heat.

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

As for the image experiment I am trying see below, this is not something I would want to take away from the pause as this works well for better camaras, I am just looking for something that is clear with a crappy camera, something that is normally found on a whoop.
This is what it look like and I find this is nice and clear for a whoop.
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

This is the actual image
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

This is why I also like the idea of having presets for LED Events in settings someone can save what they like for the type of race they are running example Outdoor, indoor and Whoops (possibly dark with leds)

HazardCreative, 2020-02-08:
I'll definitely be exploring numeric displays in the future. I don't want to pre-generate them as image files, but the image library in place should be able to print arbitrary characters.

Your exploration for staging display is helpful and I'll take it into consideration.

HazardCreative, 2020-02-11:
Save/Discard event added in e0f7e00. (These are not yet separate events.)

BoLtWD, 2020-02-11:
Fantastic... Do I need to open a new issue in regard to led indication of change of hearts that can be selected in events?

HazardCreative, 2020-02-13:
Each GitHub issue should contain only one item. It helps with managing conversations and tracking progress.

Closed 2021-03-30.

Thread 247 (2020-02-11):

USB nodes requirements

szafranski, 2020-02-11:
Consider adding additional instructions about connecting nodes directly to usb, like requirements (eg. py-serial).

ethomas997, 2020-02-13:
I think we'll add py-serial to the requirements.txt file.

szafranski, 2020-02-13:
Nice,

HazardCreative, 2020-02-13:
Does it make sense to maintain a separate text file with the optional modules?

ethomas997, 2020-02-13:
In this particular case I think the py-serial support is quite generic and should be included by default.  Also, I can envision next-generation RotorHazard hardware using serial instead of I2C, even inside the timer box.

szafranski, 2020-02-14:
Are there any benefits of using serial instead of I2C?

czw., 13 lut 2020 o 23:04 E Thomas <notifications@github.com> napisał(a):

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

ethomas997, 2020-02-14:
If we replace the 4 (or 8) Arduinos with a single 32-bit processor connected via serial link, I believe the internal communications would be faster and have fewer errors.

szafranski, 2020-02-14:
Replacing the chip is quite a big step. That actually mean the project
would be forked.

W dniu pt., 14.02.2020 o 11:58 E Thomas <notifications@github.com>
napisał(a):

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

HazardCreative, 2020-02-14:
Not necessarily; we already have serial node support.

szafranski, 2020-02-14:
So it would be like raspberry pie and 32 bit processor right?

W dniu pt., 14.02.2020 o 13:05 Hazard Creative <notifications@github.com>
napisał(a):

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

ethomas997, 2020-02-14:
> So it would be like raspberry pie and 32 bit processor right?
Yes -- thinking about improving the PCB board hardware (running basically the same software).

szafranski, 2020-02-14:
I think that new pcb design should be published for existing 4 node setup regardless of future hardware changes. There are some issues with existing PCB design.

HazardCreative, 2020-03-02:
Resolved in 3ea9a45

Closed 2020-03-02.

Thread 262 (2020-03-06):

How nodes reset should be accomplished when flashing (new PCB too)?

szafranski, 2020-03-06:
So hello - especially to devs. I have a question according to nodes flashing "system" that I developed (big word, but what do you do). As you may know that approach was proven to be working on few platforms. In a nutshell: Raspberry sends "flashing data" via UART and Arduino that was recently reset is being programmed - because that's how bootloader works. Right now each node is being reset using Raspbery GPIO. So every Arduino has a reset pin connected to some of the GPIO pins of R-Pi. I even designed a new PCB with those changes in mind - and it can be achieved with proper cabling etc. So it just works. But I was thinking recently - are all those cables necessary? And I came up with an idea, that I2C bus can be utilized for reset purposes. (I performed some prototyping and it looks promising). I will paste my discussion with Michael (few messages):

My idea:
Arduinos may be reset via "themselves" by a command from a I2C bus. How?
If some command on I2C shows (may be anything, depends of the code on the Arduino as you know) it would perform digitalWrite D2 (or any other pin) LOW - and that would be connected to the reset pin of the NEXT Arduino. Why next and not to it's own reset pin? Redundancy. After some poweroloss or any error during programming, the "resetting" Arduino would still have ability to reset the "next" Arduino and Raspberry could program it again. That way only first Arduino would require connection between reset pin and Raspberry. So resetting would be "software based" but still safe.

Michael idea (good tbh) - Arduinos should be "paired", so Arduino 1 should perform a reset on Arduino 2 etc, 2 on 1, 3 on 4 and 4 on 3. Etc.
I agree.

Conclusion:
GPIO resetting:
Pros:
- Simpler to understand
- No changes in node code (besides disabling serial)
- Already coded and tested
- If 1 nodes totally fails 1 node can’t be flashed
- Odd number of nodes is supported
Cons:
- Much more cables
- Spare LED data pin to be solved

I2C:
Pros:
- WAY less cables and “ports” required (especially important if someone won't use PCB with this feature implemented)
- Easier PCB designing and implementing
Cons:
- Odd numbers aren’t supported
- Arduino node code change required
- If 1 node totally fails 2 nodes can’t be flashed

So, devs, what do you thinks?
Cheers

szafranski, 2020-03-06:
More like "enhancing question" :)

szafranski, 2020-03-08:
I don’t know if I will have ability to perform much tests after a week or so for sometime. If you have any ideas/insights, even small - will be glad :)

Nice day!

HazardCreative, 2020-03-09:
The "pairing" strategy could make this easier to manage because it would be built into a PCB with no user intervention. However, such a strategy would not be effective should a timer be built with an even number of nodes.

The "chain" strategy allows any number of nodes to be used, but makes the system more complicated to wire up.

Either way, if a node goes down, you lose the ability to self-update two of them (the broken one and the one it signals).

szafranski, 2020-03-09:
Agree. Idk if you get that above I was comparing i2c resetting and gpio based resetting. Not i2c and “chain”. “Chain” has no benefits over i2c - I agree.

HazardCreative, 2020-03-09:
I think setting up resets via node commands makes a lot of sense, and pairing makes a lot of sense to me as well. Even with an odd number, you could still fall back to manual updating as the project has always been. I don't really like how much of the GPIO your current working implementation requires. New node command code should be pretty minimal.

Interested in thoughts from @ethomas997 and @pulquero on this.

szafranski, 2020-03-09:
Agree. Actually we can implement „backup” option which would be beneficial
with odd number of nodes too. I node can be reset via gpio. Actually that’s
all. Right?

W dniu pon., 9.03.2020 o 14:01 Hazard Creative <notifications@github.com>
napisał(a):

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

HazardCreative, 2020-03-09:
That's a really good idea, actually. I like it.

szafranski, 2020-03-09:
Meantime I will write what should be figured out:
1. What pins should be used as reset ones
(And if those pins should be same on both nodes in a pair or 1 should utilize D12 and second D2 due to physical placement etc)
2. What command should be send to make the node entered reset mode (just pulling 1 pin low for a sec - resetting another node)
3. Who will provide that functionality to the code - few lines to send/receive some command via I2C.
4. Be sure that this command won’t be sent any other time. During prototyping some byte value was sent via server start causing 1 node to reset etc - minor challenges.

Anything else?

szafranski, 2020-03-09:
I have found only one downside of this “new” way of resetting. Nodes should be flashed just once via PC before inserting in the timer. Nothing life changing - just to be aware of.

HazardCreative, 2020-03-10:
They could be done one at a time through the single GPIO reset (or at least one per pair). I expect the board would have jumpers for each nano to be temporarily connected to the GPIO reset. The user would move the jumper across one at a time during initial setup, and then leave it on the odd-numbered node if appropriate afterward.

Let's avoid D12, otherwise we would need to set up an alternate when ARDUVIDRX wiring is used. (Rare but occasionally useful for some developers). Could D8 be used? Boards using this system should not be designed to the legacy hardware address selection spec, but I'm not sure if this would mess with the initial detection of pin grounding. If not, perhaps A1.

At this point I'm pretty comfortable with this and ready to move it forward as a spec to be integrated into PCB and nano code.

Give me a bit of Arduino code that accomplishes the task and I'll make sure it gets into the current nano code in the right place. The command sent to the node could be 0x73. Obviously a different method is used for the GPIO reset, but the existing work here can be used as a guide.

szafranski, 2020-03-10:
I will carefuly read through your message later - about another points - but for now:
Consider using D12 anyway cause if it is in icsp header, user could absolutely easily connect D12 to the reset of another nano - it is provided in icsp too. So if someone would like to use this functionality without dedicated PCB or on old Delta5 PCB - jumper wires and soldering ICSP should be enough - besides connecting uart pins below the board.

Also without the special PCB, resetting via GPIO should be accomplished easily - just move the wire from gpio from one icsp header to another. What do you think? It is kind of worthy for me.

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

szafranski, 2020-03-10:
Why board with this system could not utilize legacy numbering system? No idea why that’s might be the case.

szafranski, 2020-03-10:
And yet another thought - I am not editing previous messages so you can reply via email:
Do I get it right, that right now serial won’t have to be disabled permanently? If code would look like:

if Arduino got the resetting message
    Disables serial as for a 2 minutes or till next boot
        If arduino got resetting message dedicated for it
            It resets another node in a pair

Written with python syntax but I mean on Arduino side. So effectively 2 messages would be sent - general reset and specific reset.

szafranski, 2020-03-10:
I was writing from mobile - sorry for edits

HazardCreative, 2020-03-10:
>
>
> Why board with this system could not utilize legacy numbering system? No idea why that’s might be the case.

Because no boards should be designed to the legacy spec in the first place.

szafranski, 2020-03-10:
Ok. So it is not related to this from hardware point. I get it though. Is there any new recommended way to make auto selection? Any definitive conclusions?
And what do you think about those D12 pin pros?

HazardCreative, 2020-03-10:
Refer to #252 for the auto-numbering discussion, which seems to be narrowing in.

I haven't had the time to fully understand the implications of using D12.

HazardCreative, 2020-03-12:
To clarify, the proposed spec is this:<br />
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

- One GPIO is connected to all nodes, but each has a normally-open jumper in the line
- Only ONE jumper is allowed to be closed at a time
- Node pairs connect an output pin the the paired node's reset line
- On a PCB, the jumpers should be standard header pins and not solder bridges.
- For timers with an odd number of nodes, the jumper is left in place on the last node (the one without a mate in the pairing)

For the Arduino pin, D12 can be the default if we require the alternate ArduVidRx wiring to move this assignment as well. I think this is reasonable.
For the Pi pin, GPIO 17 (pin 9) has been suggested.

I propose the above as the official spec for this.

Any final objections?

szafranski, 2020-03-12:
Sounds reasonable.

sl33pydog, 2020-03-13:
No objections from me

szafranski, 2020-03-13:
Idea: connecting RXes VCC line (usually about 3V3) to the AREF pins of Arduinos + enabling AREF as external based.

Advantages - readings "scaled" better and higher resolution of readings - if I get it right?
Disadvantages - 4 more PCB traces

What do you think?

HazardCreative, 2020-03-15:
Unrelated to node reset spec.

HazardCreative, 2020-03-15:
Specification is final and published here. https://github.com/RotorHazard/RotorHazard/wiki/Specification:-Node-hardware-reset

szafranski, 2020-03-15:
> Unrelated to node reset spec.

Right, will open new issue

HazardCreative, 2020-03-16:
#277 contains I2C write command with function stub only. Requires code to perform reset of other node and testing.

Closed 2020-04-12.

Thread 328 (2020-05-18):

RaceBand1 not working

Cuxx, 2020-05-18:
Everything is working except RaceBand 1. At first I thought the node died or I forgot to update the arduino of node 1, but I also tested RB1 on node 2,4,6 & 8, same issue. The value changes a bit, sometimes it's in the ~100 area, sometimes in the 80s. But it's always +/- 5 and you can't see any spikes during a real run.

I also reflashed the nodes again, but didn't solved the issue.
Same hardware on 2.0.2 was ok. Will downgrade to verify the hardware.

I made two videos about it:
2.1.0: https://www.youtube.com/watch?v=6tqgL1GbUJM
2.1.1: https://www.youtube.com/watch?v=env9QyYf4fU

HazardCreative, 2020-05-18:
This data is far less noisy than I would expect; RSSI is generally very messy. Can you provide more information about the setup of your race environment and how your timer is constructed?

Cuxx, 2020-05-18:
Pi4 with a prototype board from philip seidel.
8 nodes + 8 arduino pro micro (fun to upgrade with external FTDI ;))
The nodes have an extra stepdown with 3.3v
the housing is completly shielded (except the lid).

https://imgur.com/a/0Ak1dbR

HazardCreative, 2020-05-19:
RH doesn't change its operation based on frequency at all. Different RSSI levels on different frequencies is normal, but it's a little unusual that R1 is much higher. Is it possible that something else nearby is broadcasting on R1? WiFi operates in this range for example. Have you taken the timer to other physical locations?

Cuxx, 2020-05-19:
Tested it on 3 different locations and also had this issue. Downgraded to version 2.0.2 and there it was ok. But I noticed some strange behavior on rx2 (random highs for several seconds). Swapped it with rx3 and then both were strange, but mostly the original rx2 (rx3 now). after that I put it on position 8 and had these issues on rx7 & rx8 (original rx2). After removing rx2 entirely, everything is ok. Even on 2.1.1. Also tried to resolder the pins worked for rx2.

HazardCreative, 2020-05-19:
So removing a problematic RX module resolved the issue? It sounds like something in that RX5808 is faulty and it's causing noise in the system when tuned low. Please report back if replacing the hardware resolves it.

Cuxx, 2020-05-19:
Hi, I had an awesome training session today with 40 heats & 4 pilots (node 1-4 with RB 1,3,5,7). The system had only 7 nodes (without the original rx2). RX 5-7 were disabled (no frequency).

I just inserted a new rx and everything is still fine, even after one hour of idleing. I never expected that a dead rx5808 could cause such problems. Thanks for your time & help ❤️

HazardCreative, 2020-05-20:
Awesome. Glad we got it solved!

Closed 2020-05-20.

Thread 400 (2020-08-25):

Split times not working: always same speed and no showing on results

rodcar125, 2020-08-25:
Hi all!

Last race I finally set up a race with two systems for split timing. Mainly i want to calculate speed on a sprint as part of the track I flew. Gate 1 is start/finish with master timer and 20m later is gate 2 with timer 2 on a straight. Config file attached and configured with the 20m and slave ip address. Comms were up between timers as they were showing the splits on the current race. The issue is that all the split times seem to be the same with a calculated speed of 0.06 which is not correct. every round that we ran was the same. Also, although it would show the split times on the current race page, it does not save it on the results page.

Passes were always Gate 1 then gate 2 and recorded correctly on  master timer as you can see as an example on picture last2series.png with the race start time and on the log file started at the same time at 17:33:01 and 17:42:56

attached config, database, log and picture from the last run recorded with OBS.
Thanks guys!!

[SplitTimes_Issue.zip](https://github.com/RotorHazard/RotorHazard/files/5120857/SplitTimes_Issue.zip)

ethomas997, 2020-08-25:
I've recently posted a PR (#399) that may help.  I've not done any testing with the speed feature, so if you'd like to try it out and report back, that'd be great.

rodcar125, 2020-08-25:
this was run with 2.3.0 dev-1 but cant remember when did I do the update so i cannot tell if your PR is on the tested SW. Ill install master on both timers now and retest over the weekend and report back. Thanks for the prompt reply (:

ethomas997, 2020-08-25:
The PR is separate from the 'master' branch, so you wouldn't have run it via the 'master' before.  However I just merged PR #399 into the 'master' branch and updated the version to "2.3.0-dev.3", so if you're running that version then you'll be running with those split-timer updates.

rodcar125, 2020-08-25:
Ohh ok, didn’t know that hehe, still learning the github ways, it’s kind of confusing for me /:

Yesterday I upgraded both timers to 2.3.0-dev.2 and seemed to me that was already working (with simulated passes) but I’m not sure about the innards so I will update again later today and report back. Thanks so much for letting me know (:
Best regards!

Rodrigo C

rodcar125, 2020-08-26:
Hi!

Just installed 2.3.0-dev.3 on both timers. I always start the slave first so when the master starts and starts looking for the salaves, they are already there ready to connect.

Somethings happening on the slave side that it fails with the following error...
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
Logs from master and slave:
[rh_20200826_174628_Master.log](https://github.com/RotorHazard/RotorHazard/files/5133055/rh_20200826_174628_Master.log)
[rh_20200826_174608_Slave.log](https://github.com/RotorHazard/RotorHazard/files/5133056/rh_20200826_174608_Slave.log)

Best regards!
RC

ethomas997, 2020-08-28:
@rodcar125 Good catch there; thanks for testing and reporting.  I've updated the 'master' branch to have a check for that (so there should be a log.info message in that case and not an error), and the update for PR #402 is also in there.

rodcar125, 2020-08-28:
@ethomas997 glad i can help out in some minor way (:
So, this check should also be done when trying to set up the frequency from the frequency setup tab, right? I mean, if I change the frequency of node 5-8 on master, it shouldn't send the update to the slave since it is a 4 node system, right?

ethomas997, 2020-08-28:
@rodcar125 In that case the master will still send the frequency update to the slave, and the slave will send a message to the log file saying the node index is out of range, and do nothing else.

rodcar125, 2020-08-28:
@ethomas997 just tested the starting thread on the updated master and I think is working all right. I might have a couple hours left today and test it out with an actual drone for speed and frequency changes and callouts. Ill let you know how it went.
here are the new logs from the starup with the updated master.

[rh_20200828_155359_master.log](https://github.com/RotorHazard/RotorHazard/files/5144191/rh_20200828_155359_master.log)
[rh_20200828_155339_slave.log](https://github.com/RotorHazard/RotorHazard/files/5144192/rh_20200828_155339_slave.log)

HazardCreative, 2020-10-16:
Can we confirm this issue is resolved?

Closed 2020-10-16.

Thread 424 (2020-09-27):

Enhancement: Starting Condition 1st Lap Counting

sl33pydog, 2020-09-27:
People may not run races this way but is there a way to run a race where you don't fly through the timer to start the race?  We ran a race where the start platform was off on the side of the start gate.  Pilots ran through their first lap and Rotorhazard would see that as a hole shot.  This made it so that all pilots had 1 less lap then they should have.

Live time has it where you either count the 1st lap and disregard the hole shot or that it needs the first lap for hole shot to keep the laps consistent.

I understand the need for both and I understand both have consiquences.  On one side forcing pilots through the start gate needs a good line and decent pilots so they don't crash on the start gate.  The other insures pilots get on their lines faster but messes up the fastest lap since that first lap might be their slowest.  I know people will not do it this way generally but would love to have this as an option.

So I propose that there should be two start conditions:

1. Start Gate: Passing through the start gate produces a hole shot and starts the 1st lap.  This is currently the way Rotorhazard is set up.

2. Shotgun Start: As soon as the timer starts, the 1st lap has initiated and when pilots go through the track over the timer the 1st lap is counted.  Hole shot is disabled.  Pilots don't go through the start gate but on a parallel path that with the correct layout ensures even beginners a chance to get through gates or flags.  This can be viewed like a street race or nascar.

HazardCreative, 2020-09-27:
My biggest question is: why is the current behavior an issue for you? You're still collecting that first crossing time. Since RH doesn't yet support staggered start, that time is added to the pilot's total race time. Is it just a terminology issue ('hole shot' vs 'lap 0')?

When a course is set up this way, that first lap is necessarily not the same as others. I'd argue that there's good reason it should not be considered for many of the stats like fastest lap and 3 consecutive laps.

sl33pydog, 2020-09-27:
The current behavior isn't an issue with me.  It's with the many groups I've flown with.  Way back in the day I started with using the timing gate as the first gate to fly through but the groups noticed a trend.  With experienced pilots we saw too many mid air collisions either before or in the timing gate.  With novice pilots we saw them either take 2 minutes to figure out going through the timer or crashing into it without running into others.  When the groups started to switch to this new way where a side track paralleled the start gate we saw very few if not any mid airs from pilots unless they grouped themselves in the race and novice pilots finally got some momentum (even though they would crash later on a flag or another gate if we put them there).  So when we ran the race with fastest three consecutive laps I didn't match with live time with some of the pro pilots who would go full throttle and kill their batteries after 3 laps.  Rotorhazard only saw 2 laps.  And for our A mains for first to three laps it did the same.  Live time would tell them to land where Rotorhazard said they had 1 more lap.  A reason why I didn't use the audio from Rotorhazard.

I would agree and disagree with that.  I agree that yes the first lap isn't the same but I disagree that doesn't also happen using it in the default way.  I definitely want to test which way is more consistent.  In our race with the pro pilots they were showing a 4 second difference between that first lap and last lap but it was also showing that each lap they did got faster.  I reckon we would see similar results to the default method.

Really what happened was the system gave them a practice lap that didn't add to their lap count but added a full lap worth of time to their total time.  This would be fine for shorter tracks but we tend to make courses for novice pilots that are 3 laps long in 2 minutes and for pro guys they only go three laps just so they don't destroy the battery.

HazardCreative, 2020-09-27:
Essentially what you're looking for is to have the system record a hole shot of 0:00 for all when a race begins. Is that correct?

Not trying to be difficult here, but every additional option adds cognitive overhead to the system and erodes how simple it is to use and manage. The race organizer's experience is more important to me than having every possible option. So for each new option I take a hard look at whether it will provide a significant benefit or if there's a better way to approach it that doesn't mess with the UI as much. It's not about how difficult it is to add the feature (which it probably wouldn't be).

With the start position just before the gate, it's true that the first lap is often slower. But I don't think anyone would argue that it should not count as a lap—the pilot has definitely completed the entire course. When the pilots do not complete the start gate, they have not run the entire course line. You're no longer comparing apples to apples.

If the first-lap course is shorter/faster, this weights the first lap heavier than others. You'll reward a very aggressive start, and probably cause more crashes and collisions. I'm not sure all race directors would recognize this? The pilot's experience might weigh in this as well.

If you look at the MultiGP global qualifier course, particularly 2019, you'll see a good in-between way to handle this: The launch happens one or two corners before the gate, as a lead-in to the first crossing. Pilots without experience to complete a timing gate won't be solved by moving it later in the course.

sl33pydog, 2020-09-27:
Lol you're not being difficult at all.  It's necessary to discuss things in order for the product to have it's best income whatever direction it needs to take.  I'm with you on not complicating things.  Livetime is like android you can tweak everything you want but can get overwhelmed easily in the start.  Rotorhazard is like apple, a lot of it is behind the scenes and the UI creates a straight forward experience that even beginners can pick up with out too many issues.

Essentially what I was looking for was the the system to count the first lap as a lap.  Hot shot doesn't matter here, just that the first time a pilot goes over the timer that the lap be counted as 1 completed lap.  The length of the course is the same just the start is offset to the side.  Yes it does reward more aggressive starts but it does help the novice pilots too.  Generally the tracks have flags after the start gate where we are allowing groups to generally thin out.  People go high, low, wide, or short around flags as opposed to going through a 6'x6' opening where people try to go through the center.

So I like the idea of having the start somewhere 1 to two steps back but again if it's gates we get the same issues.

I do realize the importance of the first recorded spike. I used it in the race to see if someone switched their quads so I could spot them during the race.  Usually indicated by a lower rssi.

This change really benefits large tracks.  Compact tracks don't have the benefit of a runway or offset track.

Also to your point about spectator involvement wouldn't a more aggressive start turn more heads 😉.

Closed 2020-10-26.

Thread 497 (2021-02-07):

python 3 doesn't detect correct number of installed nodes

Aaronsss, 2021-02-07:
I have upgraded my installation to run python 3. The server no longer detects the correct number of nodes installed on the PCB.

I have a 6 node timer and the web interface shows 8 nodes available when Rotorhazard is run by python 3, the issue goes away when switching back to python 2

I am running the RotorHazard version 2.3.1

HazardCreative, 2021-02-07:
What does your log look like?

Aaronsss, 2021-02-07:
Having looked at it it seems like python 3 is using 'Using mock hardware interface' am I just being a noob?

Logs below from both versions

**Python 2**
RotorHazard v2.3.1
Release: 2.3.1 / Server API: 29 / Latest Node API: 25
Host machine: Raspberry Pi 3 Model B Rev 1.2
Host OS: Linux 5.4.83-v7+
Host machine is 'LapTimer' at 192.168.1.120
Using configuration file 'config.json'
Using log file: logs/rh_20210207_001402.log
Loaded module i2c_helper
Loaded module i2c_node
Loaded module serial_node
Searching for I2C nodes...
...I2C node 1 found at address 8
...I2C node 2 found at address 10
...I2C node 3 found at address 12
...I2C node 4 found at address 14
...I2C node 5 found at address 16
...I2C node 6 found at address 18
...No I2C node at address 20
...No I2C node at address 22
Node 1: API_level=25, Freq=1111, EnterAt=85, ExitAt=70
Node 2: API_level=25, Freq=5695, EnterAt=101, ExitAt=87
Node 3: API_level=25, Freq=1111, EnterAt=119, ExitAt=109
Node 4: API_level=25, Freq=1111, EnterAt=124, ExitAt=121
Node 5: API_level=25, Freq=1111, EnterAt=104, ExitAt=94
Node 6: API_level=25, Freq=1111, EnterAt=116, ExitAt=105
Number of nodes found: 6
Loaded module linux_sensor
Core temperature available
Set Profile to '3'
LED: selecting library "neopixel" (older)
LED: hardware GPIO enabled, count=150, pin=10, freqHz=800000, dma=10, invert=False, chan=0, strip=GRB/528384
Loaded module led_handler_strip
Running http server at port 5000
Interface: Starting background thread

**Python 3**
RotorHazard v2.3.1
Release: 2.3.1 / Server API: 29 / Latest Node API: 25
Host machine: Raspberry Pi 3 Model B Rev 1.2
Host OS: Linux 5.4.83-v7+
Host machine is 'LapTimer' at 192.168.1.120
Using configuration file 'config.json'
Using log file: logs/rh_20210207_001311.log
Loaded module i2c_node
Loaded module serial_node
Using mock hardware interface
Number of nodes found: 8
Loaded module linux_sensor
Core temperature available
Set Profile to '3'
LED: disabled (no modules available)
Running http server at port 5000
Interface: Starting background thread.

ethomas997, 2021-02-07:
Have you done the pip-requirements install with the 'pip3' command, like this?:
```
cd ~/RotorHazard/src/server
sudo pip3 install -r requirements.txt
```

Aaronsss, 2021-02-07:
Yep, without it the server wouldn't boot.

I tested with python 3.7.3 (I think). Am upgrading to python 3.9.1 to see if that helps

ethomas997, 2021-02-07:
There are some code updates that may help with this.  If you'd like to try them out, please upgrade to the current "2.3" branch using the commands below and try it out.  (Before updating, any currently-running RotorHazard server should be stopped).
```
cd ~
wget https://codeload.github.com/RotorHazard/RotorHazard/zip/2.3 -O temp.zip
unzip temp.zip
mv RotorHazard RotorHazard.old
mv RotorHazard-2.3 RotorHazard
rm temp.zip
cp RotorHazard.old/src/server/config.json RotorHazard/src/server/
cp RotorHazard.old/src/server/database.db RotorHazard/src/server/

cd ~/RotorHazard/src/server
sudo pip install --upgrade --no-cache-dir -r requirements.txt
```
This will update the RH server version to 2.3.2.

Aaronsss, 2021-02-07:
Thanks @ethomas997, using the above seems to have resolved the issue. I ran it on python 3.7.3

ethomas997, 2021-02-07:
Ah great; thanks for testing and reporting.  We'll be posting a 2.3.2 version with these updates.

HazardCreative, 2021-02-10:
Closed by f0c571d .

frizzle101101, 2021-03-25:
i am quite the current instructions on the release page are incorrect because just attempted to set up a pi with those instructions and came here to find the solution please can you update the 2.3.2 release page instructions

Closed 2021-02-10.

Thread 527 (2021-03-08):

Rotorhazard locked up, stopped updating laps, sending voice prompts, and required restart (Too many files open message)

RogerBFPV, 2021-03-08:
After 5 hours of racing, stopping, starting new heats, when an interesting symptom occurred:
During a race, new laps stopped being updated at the browser..

Looking at the browser, we could see the RSSI graphs for a pilot rise and fall, but the lap would not show up and there was no voice prompt..

When the race was over, (it was a heads up race first to 3 laps), I pressed stop race, and save laps..  But the save laps never returned..

I tried refreshing the browser, but that didn't do much, (It would go back to the 'save laps' button, but pressing it would not. So I was unable to progress to the next race..

I then went into settings, and attempted to 'reboot' the pi, but the reboot did not occur..(The browser indicated it was rebooting, but  when connecting again, the system was in the same state)..

I then went and unplugged/replugged the power to the pi..

AMAZING enough, the laps for that race were indeed saved!!! so that was good news.. and the rest of the day ran without issue.

The there are 'ERROR' s in the log around the time of the failure..(unable to open database file) So I'll attach that log. Around timestamp of 05:50:11. and Too many open files at 05:50:29... .

[rh_20210305_233320.log](https://github.com/RotorHazard/RotorHazard/files/6098828/rh_20210305_233320.log)

RogerBFPV, 2021-03-08:
This was version 2.3.0:
021-03-05 23:33:20.844: __main__ [INFO] Release: 2.3.0 / Server API: 29 / Latest Node API: 25
2021-03-05 23:33:20.844: RHUtils [INFO] Host machine: Raspberry Pi 3 Model B Rev 1.2
2021-03-05 23:33:20.845: RHUtils [INFO] Host OS: Linux 4.19.66-v7+

HazardCreative, 2021-03-08:
Thanks for the report. We will definitely be looking into this and see what we can uncover. Are we able to get the database file as well?

RogerBFPV, 2021-03-09:
[database.db.zip](https://github.com/RotorHazard/RotorHazard/files/6111228/database.db.zip)
database file.

HazardCreative, 2021-03-15:
Confirming there is an issue here, which appears to be inherited all the way back from Delta5. Thanks for providing logs and database. Restarting RH will clear out the buildup of unused file handlers so as a temporary workaround you could look for a place to break and restart every couple hours of racing. We are working to resolve it.

Technical: File handlers are created when the database is called. When this happens via a submodule callback to main (during processing of a lap record) the file handler is not closed.

Closed 2021-03-20.

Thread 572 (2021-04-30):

Voltage reading on Node 1

frizzle101101, 2021-04-30:
This is a mod i have done to get a voltage reading in node 1 to use a pizo buzzer directly connected to a digital pin, if this is of interest to development i can try to start a pr for hardware-based buzzer and voltage sense capabilities(no spi, i2c here), maybe separate idea, and pr, with a buzzer on each node for different capabilities as used by chronous hardware

frizzle101101, 2021-05-01:
Duplicate of #88

Closed 2021-05-01.

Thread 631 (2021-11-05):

System Lag/Hang

Strangedave, 2021-11-05:
Repost from FB Groups

Ok, this is gonna be a long one. So I have been running a rotor hazard timer for probably 2 years now. I have had occasions where we have a lot of pilots and the timer feels bogged down after 8-9 rounds with 3 heats and 4-5 pilots per heat. This week we had 18 pilots for whoop racing and the timer literally locked up at like 3 rounds. I have a backup that I bought from another club. That system stopped working also. I checked voltage and changed network cables. We are POE, so I wanted to make sure that was not the issue. Is there any one here that might be able to help me debug these timers. Whoop season has some pretty big turnouts here, and I'm sure you all know how things can turn ugly when the timer isn't running. Both rigs are basically the same except one is pi4 and the other is pi 3b. The pi3 machine has been basically unusable. The pi4 can get through a night pretty well, but will be slow by the end of the night. Another guy in the group is building a blue pill setup, so we will get a chance to see how that works in the next few days. We did ssh into both systems tonight and cpu usage was always below 10%. So I'm kinda stumped.
**To Reproduce**
We tested the main timer and revised the 2nd timer to be a split unit in the config.json file. We ran 5 pilots for 8 rounds without any issue. The secondary/split unit did not run, I have no idea why. the main unit ran acceptably though. I am going to get 5 rigs on different channels and try and generate 4 heats with 5 pilots tonight. to see if I can make the system hang.

**Expected behavior**
Just needs to run. The pilots get antsy when we are waiting for the timer to start the race. at the event in question the start button was clicked, and the start tones would not start the race for 30-40 seconds in some instances.

**Log Dump**
Attached for both systems.

**Desktop (please complete the following information):**
 - Windows 10 Pro 20h2
 - Chrome
 - rh 3.0

**Smartphone (please complete the following information):**
We did not connect via smart phone or tablet
 -
[Main rh_logs_20211105_124602.zip](https://github.com/RotorHazard/RotorHazard/files/7487956/Main.rh_logs_20211105_124602.zip)
]

**Additional context**
Add any other context about the problem here
[Secondary rh_logs_20211105_124806.zip](https://github.com/RotorHazard/RotorHazard/files/7487975/Secondary.rh_logs_20211105_124806.zip)
.

HazardCreative, 2021-11-08:
Have you tested with 3.1? There were considerable improvements to performance.

Strangedave, 2021-11-08:
I have not, I’ll try and throw it on the backup box for testing at our Tuesday night event.

ethomas997, 2021-11-08:
My recommendation would be to simplify things: run a single unit (no split timer) on the latest beta code, and see if you can get it to act up.  If it does then check the log file for any errors, etc at the time of the problems, and you could also post it here.

Are you networking through a switch or router?  I've seen freezing and lagging when there are network issues.

Strangedave, 2021-11-10:
Ok, we did a bunch of diagnostic, hundreds of laps, and rounds of testing, and everything worked perfectly. Until tonight, the big event. once the timer was up and running and we were ready to kick off the first heat, the whole thing locked up. same as last time. This time we had everything we needed to check all the temps, voltages. we worked back through the whole system while one of the guys ran the event on our laprf. Turns out the entire problem was the router. We swapped in for a spare and WABAMO. we are back in business. Sorry for bugging you guys with my equipment issues. It also gave us a chance to remember just how much it sucks to try and time whoops with a laprf. Thanks for all of your time and effort, and again I'm sorry we didn't catch this earlier.

ethomas997, 2021-11-10:
Called it -- network issue. :]  Hey, no worries, glad it's working better for you.

Strangedave, 2021-11-10:
I literally had the second Router spun up and ready, just wanted to make sure we were finding the issue.  But you were correct. Thanks for the help.

HazardCreative, 2021-11-10:
Thanks so much for putting in the effort to nail down the problem.

Strangedave, 2021-11-10:
It’s the least we could do. Thanks for all of your hard work!

Closed 2021-11-10.

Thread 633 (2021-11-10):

Weird issues with power on the newest Raspbian 11 (Bullseye)

szafranski, 2021-11-10:
Raspberry Pi 4 is not willing to boot when powered using GPIO pins (the way we expect users to do it).
It is powering on with no problem when connected using USB-C. To be confirmed by someone else.

Platform:
Raspberry Pi 4 with Raspbian 11 (Bullseye)

ethomas997, 2021-11-21:
I've tested with an RPi4/Bullseye powered via pins on the 40-pin connector; seems to run fine for me.

szafranski, 2021-11-21:
My Pi boots no problem if powered via GPIO pins when Buster is in use. If SD card (or USB) contains Bullseye, it is not willing to boot. Checked multiple times. But Dave Just seems to do not have any issus - as you. Maybe something very weird is going on on my Pi. Some eeprom-related power issues? Idk, mega-weird but seems that it is not anything that will affect other users, so maybe we should leave that issue opened, so users with that problem had a hint that it happened to others. At least for next month or so, because many people will update their OS I suppose. If you just want to close the issue - no problem for me too.
|One question - have you tried it with fresh install of Bullseye or after updating from Buster?

ethomas997, 2021-11-21:
I did a fresh install of Bullseye

szafranski, 2021-11-21:
Ok, so same as me. Nothing else to ass from my side then.

WombatControl, 2022-01-03:
I am having the same issue right now - the system refuses to boot up when the GPIO pins are connected, even if power is being applied to USB-C instead. My thought was that enabling I2C through raspi-config might be a fix, but even after powering solely from USB-C with I2C enabled the Pi will not boot from the GPIO pins. This is on a Pi4 running the latest Bullseye ISO.

szafranski, 2022-01-03:
Have you tried with another/previous raspbian?

WombatControl, 2022-01-03:
Yes, the system works just fine with Buster, so there has to be something in Bullseye that causes an issue. It could be limited to just a particular hardware revision of the Pi4 - I will try with another Pi and do some testing to see if that may be the case.

ethomas997, 2022-01-03:
It may be that the Pi with Bullseye is drawing more power during the bootup and it's too much for the power circuit.  I'm not able to reproduce the issue, so I can only really guess.  Is there anything non-standard about your setup?  The 5V power comes from the regulator at U12, so you could try replacing that, and you could try a different ribbon cable.

pulquero, 2022-01-03:
I used to get low power warnings on Buster. I found I was getting something like a 0.2V drop over the power cables. Switching to thicker cables resolved the problem.

ethomas997, 2022-04-17:
Closing this issue; feel free to reopen if needed

Closed 2022-04-17.

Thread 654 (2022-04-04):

Nodes running but not picking up RF

jayybeerc, 2022-04-04:
This is an open issue as a request for tips please.
Firstly, amazing work by the contributors, first class and very much appreciated.
My issue as the title suggests relates to the nodes running (Showing a trace RF value) but not picking up RF transmitted by anyone of my quads.  My trace RSSI is on average 44 and the node address code is correctly set 1 to 4 (As per the excellent docs).
I am am running version 3 of the server plus relevant node code.
The system is so close to working and is extremely feature rich so this node issue is quite frustrating.
Any help, tips, advise, guidance would be very welcome and again many thanks, great work.

jayybeerc, 2022-04-04:
Outstanding. Great responses, many thanks. Well, I am getting multiple 0xFF so I will now continue and do the hardware SPI mod. My 5808's are new and the dates supposedly have the SPI mod. The sample test code is great and proves what needs to be done. I will post an update as to the result. Thanks again all, fantastic support.

martinglass, 2022-04-04:
> Outstanding. Great responses, many thanks. Well, I am getting multiple 0xFF so I will now continue and do the hardware SPI mod. My 5808's are new and the dates supposedly have the SPI mod. The sample test code is great and proves what needs to be done. I will post an update as to the result. Thanks again all, fantastic support.

Glad it's helped.

FYI, pin 7 on the RTC6715 needs to be HIGH for SPI mode, see
[https://github.com/martinglass/Testing-RX5808-module/blob/main/src/RTC6715-RichWave.pdf](https://github.com/martinglass/Testing-RX5808-module/blob/main/src/RTC6715-RichWave.pdf)

jayybeerc, 2022-04-04:
Update:
All working and very impressive chaps. The nodes do need a good tune but so far so good. I need to test the system with my racing club both outdoor and indoor. A lot of flyers will be very happy. The features and functions are impressive. Your time and dedication to produce such a great project is humbling. I will let you know how further tests go. Many thanks again.

jayybeerc, 2024-01-03:
Hello once again. Firstly I wish to express mine and others deep gratitude for all the hard work put in by your good selves. I hope and trust you will be pleased to hear that we have since April 2022 used version 3 of the timer up until last week, so a very happy bunch of flyers for the last 1.5 years. We have found that the timer at version 3 has been stable and works very well, this being from 5" outside racing to indoor whoop meets. We simple could not survive without it. So again, many thanks. OK, so as the timer is so popular I have extended it from a 4 ch to 8ch device. We have decided to remain at version 3 (I will upgrade in the future) as for us it works well, we just need more capacity. ENQUIRY: I read in the version 4 docs that the Arduino node code remains unchanged over the past versions, so have flashed my new 4 nodes, changing the ID number in the header file starting at 5 through to 8. However now when I run the timer I am getting errors in the logs, for example:

2024-01-03 20:36:53.440: __main__ [INFO] Release: 3.0.0 / Server API: 30 / Latest Node API: 35
2024-01-03 20:36:53.441: RHUtils [INFO] Host machine: Raspberry Pi 4 Model B Rev 1.4
2024-01-03 20:36:53.441: RHUtils [INFO] Host OS: Linux 5.10.60-v7l+
2024-01-03 20:36:53.442: RHUtils [INFO] Python version: 3.7.3 (default, Jan 22 2021, 20:04:44)
2024-01-03 20:36:53.442: __main__ [INFO] Host machine is 'raspberrypi' at 192.168.1.101
2024-01-03 20:36:53.443: Config [INFO] Using configuration file 'config.json'
2024-01-03 20:36:53.443: __main__ [INFO] Using log file: logs/rh_20240103_203653.log
2024-01-03 20:36:53.596: Plugins [INFO] Loaded module i2c_helper
2024-01-03 20:36:53.700: Plugins [INFO] Loaded module i2c_node
2024-01-03 20:36:53.704: Plugins [INFO] Loaded module serial_node
2024-01-03 20:36:53.706: i2c_node [INFO] Searching for I2C nodes...
2024-01-03 20:36:53.707: i2c_node [INFO] ...No I2C node at address 8
2024-01-03 20:36:53.724: i2c_node [INFO] ...No I2C node at address 10
2024-01-03 20:36:53.740: i2c_node [INFO] ...No I2C node at address 12
2024-01-03 20:36:53.757: i2c_node [INFO] ...No I2C node at address 14
2024-01-03 20:36:53.865: i2c_node [INFO] ...I2C node 5 found at address 16, API_level=35, fw_version=1.1.4, fw_type=Arduino, fw_timestamp: Jan  3 2024 13:37:41
2024-01-03 20:36:53.972: i2c_node [INFO] ...I2C node 6 found at address 18, API_level=35, fw_version=1.1.4, fw_type=Arduino, fw_timestamp: Jan  3 2024 13:41:28
2024-01-03 20:36:54.078: i2c_node [INFO] ...I2C node 7 found at address 20, API_level=35, fw_version=1.1.4, fw_type=Arduino, fw_timestamp: Jan  3 2024 13:43:55
2024-01-03 20:36:54.185: i2c_node [INFO] ...I2C node 8 found at address 22, API_level=35, fw_version=1.1.4, fw_type=Arduino, fw_timestamp: Jan  3 2024 13:44:38
2024-01-03 20:36:54.598: __main__ [INFO] Number of nodes found: 4
2024-01-03 20:36:55.199: Plugins [INFO] Loaded module bme280_sensor
2024-01-03 20:36:55.218: Plugins [INFO] Loaded module ina219_sensor
2024-01-03 20:36:55.221: Plugins [INFO] Loaded module linux_sensor
2024-01-03 20:36:55.246: linux_sensor [INFO] Core temperature available
2024-01-03 20:36:55.605: __main__ [INFO] Set Profile to '2'
2024-01-03 20:36:57.752: Plugins [INFO] Loaded module data_export_csv
2024-01-03 20:36:57.756: Plugins [INFO] Loaded module data_export_json
2024-01-03 20:36:57.915: __main__ [INFO] Running http server at port 5000
2024-01-03 20:36:59.231: BaseHardwareInterface [INFO] Interface: Starting background thread
2024-01-03 20:36:59.258: RHInterface [ERROR] Exception in RHInterface update_loop():
Traceback (most recent call last):
  File "../interface/RHInterface.py", line 198, in update_loop
    self.update()
  File "../interface/RHInterface.py", line 347, in update
    data_logger = self.data_loggers[node.index]
IndexError: list index out of range
2024-01-03 20:37:00.285: RHInterface [ERROR] Exception in RHInterface update_loop():
Traceback (most recent call last):
  File "../interface/RHInterface.py", line 198, in update_loop
    self.update()
  File "../interface/RHInterface.py", line 347, in update
    data_logger = self.data_loggers[node.index]
IndexError: list index out of range

Any insight or help very much appreciated please.
Overall we just want to keep what we have and add the extra 4 channels.
In advance, thanks.
JB

HazardCreative, 2024-01-03:
The timer you have booted here does not have nodes 1–4, only 5–8. The Arduino-based setup requires nodes be available in order, starting from 1.

ethomas997, 2024-01-04:
That hardware is pretty old so we don't have good documentation on it; there's really just this one page:

https://github.com/RotorHazard/RotorHazard/blob/main/doc/Timer%20Build%20with%20Arduinos.md

If you parallel connect the lines for GND, SDA and SCL between the boards then I think it should work.  Each board will need power as well.

HazardCreative, 2024-01-05:
> OK I have 2 Delta5 boards (4ch per board) and it is not possible to run them in isolation, so this can be ruled out.

Currently that is correct. We may be able to fix the error you're getting. Would you isolate it into a new issue, please?

> Do you have a wiring schematic showing the required links between the boards?

No; the Delta5 board predates the RotorHazard project and the schematics weren't included. Your best bet with it is to start the way ET suggested and check with a multimeter that the connections match the [required wiring](https://github.com/RotorHazard/RotorHazard/blob/main/doc/Timer%20Build%20with%20Arduinos.md#system-assembly). You could also migrate your components over to the [RH Arduino PCB](https://github.com/RotorHazard/RotorHazard/blob/main/resources/PCB/README.md), which has a clearly labeled header to connect between two PCBs.

I'm *specifically not recommending this* as I don't think it's worth the risk or effort, but the RH PCB can auto-number nodes at startup. If you put a switch across JP2 on PCB2, you could create a system that numbers itself from either 1-4 or 5-8 based on the position of that switch at boot.

jayybeerc, 2024-01-05:
> Currently that is correct. We may be able to fix the error you're getting. Would you isolate it into a new issue, please?
No need I have worked around the problem.

I must remark and express my thanks for the replies and your valued time.
I now have a working timer that has migrated from 4 to 8 ch's.
I know and appreciate that I have been working with older software revisions and hardware but the object was to take a 4ch device and simple extend to 8 as the original system was and still is fit for purpose.
I am not sure if anyone is interested in what was required to get it up and running but after a few hundred lap tests on nodes 5 to 8 (I only have 1 extra RX5808 chip that I moved to each channel) all seem OK.
So for now the plan is to run with this version and migrate the hardware and upgrade the software to the latest when convenient.
Finally, thanks again for all the replies and this amazing project.
Much appreciated.

Closed 2022-05-27.

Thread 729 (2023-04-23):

Starting Up with no modules ... unable to use server to test RH server

martinglass, 2023-04-23:
**Describe the bug**
Connecting the Pi to an STM32 PCB (in this case 8-way), with no RX5808 modules attached and/or no BPill in situ, the RH Server won't start up, for example to test hardware or to run mode nodes.

Is it possible to get mock nodes instead of this error failure?

**Expected behavior**
If no PCB is connected the server starts up with mock nodes, and the logs would show  ...
_Unable to initialize nodes via RHInterface:  Unable to read frequency value from node 1
Using mock hardware interface_

The full log  would look like this
_RotorHazard v4.0.0-dev.3
Release: 4.0.0-dev.3 / Server API: 39 / Latest Node API: 35
Host machine: Raspberry Pi 3 Model B Rev 1.2
Host OS: Linux 6.1.21-v7+
Python version: 3.9.2
Host machine is 'rotorhazard' at 192.168.0.148
Loaded plugin module rh_led_handler_graph
Loaded plugin module rh_heatgenerator_standard
Loaded plugin module rh_data_export_json
Loaded plugin module rh_led_handler_character
Loaded plugin module rh_heatgenerator_ladder
Loaded plugin module rh_led_handler_bitmap
Loaded plugin module rh_data_export_csv
Loaded plugin module rh_led_handler_strip
Using configuration file 'config.json'
Using log file: logs/rh_20230423_130956.log
Loaded module i2c_helper
Loaded module i2c_node
Loaded module serial_node
Searching for I2C nodes...
Unable to initialize nodes via RHInterface:  Unable to read frequency value from node 1
Using mock hardware interface
Number of nodes found: 8
Loaded module bme280_sensor
Loaded module ina219_sensor
Loaded module linux_sensor
BME280 found at address 0x76 ('i2c:0x76')
BME280 found at address 0x77 ('i2c:0x77')
INA219 found at address 0x40 ('i2c:0x40')
INA219 found at address 0x41 ('i2c:0x41')
INA219 found at address 0x44 ('i2c:0x44')
INA219 found at address 0x45 ('i2c:0x45')
Core temperature available
No 'database.db' file found; creating initial database
Pilot added: Pilot 1
Pilot added: Pilot 2
Pilot added: Pilot 3
Pilot added: Pilot 4
Pilot added: Pilot 5
Pilot added: Pilot 6
Pilot added: Pilot 7
Pilot added: Pilot 8
Database pilots reset
Heat added: Heat 1
Database heats reset
Database saved races reset
Database set default profiles
Database reset race formats
Database race classes reset
Reset global settings
Frequency set: Node 1 B:R Ch:1 Freq:5658
Frequency set: Node 2 B:R Ch:2 Freq:5695
Frequency set: Node 3 B:F Ch:2 Freq:5760
Frequency set: Node 4 B:F Ch:4 Freq:5800
Frequency set: Node 5 B:R Ch:7 Freq:5880
Frequency set: Node 6 B:R Ch:8 Freq:5917
Frequency set: Node 7 B:None Ch:None Freq:0
Frequency set: Node 8 B:None Ch:None Freq:0
Database initialized
Set Profile to '1'
Node enter-at set: Node 1 Level 90
Node enter-at set: Node 2 Level 90
Node enter-at set: Node 3 Level 90
Node enter-at set: Node 4 Level 90
Node enter-at set: Node 5 Level 90
Node enter-at set: Node 6 Level 90
Node enter-at set: Node 7 Level 90
Node enter-at set: Node 8 Level 90
Node exit-at set: Node 1 Level 80
Node exit-at set: Node 2 Level 80
Node exit-at set: Node 3 Level 80
Node exit-at set: Node 4 Level 80
Node exit-at set: Node 5 Level 80
Node exit-at set: Node 6 Level 80
Node exit-at set: Node 7 Level 80
Node exit-at set: Node 8 Level 80
Updated calibration with best discovered values
Unable to find java; for IMDTabler functionality try:
sudo apt install default-jdk-headless
VRx Control disabled: no registered controllers
Running http server at port 5000_

**Instead the Log Dump looks like this**
_RotorHazard v4.0.0-dev.3
Release: 4.0.0-dev.3 / Server API: 39 / Latest Node API: 35
Host machine: Raspberry Pi 3 Model B Rev 1.2
Host OS: Linux 6.1.21-v7+
Python version: 3.9.2
Host machine is 'rotorhazard' at 192.168.0.213
Loaded plugin module rh_led_handler_graph
Loaded plugin module rh_heatgenerator_standard
Loaded plugin module rh_data_export_json
Loaded plugin module rh_led_handler_character
Loaded plugin module rh_heatgenerator_ladder
Loaded plugin module rh_led_handler_bitmap
Loaded plugin module rh_data_export_csv
Loaded plugin module rh_led_handler_strip
Using configuration file 'config.json'
Loaded module i2c_helper
Loaded module i2c_node
Loaded module serial_node
Serial node (with zero modules) found at port '/dev/serial0', API_level=35, baudrate=921600, fw_version=1.1.4, fw_type=STM32F1, fw_timestamp: Mmm dd yyyy hh:mm:ss
        (alt - without BPill in situ: Unable to fetch revision code for serial node at "/dev/serial0")
Unable to initialize nodes via RHInterface:  Unable to read frequency value from node 1
Unable to initialize specified serial node(s): ['/dev/serial0']
Exception ignored in: <function _removeHandlerRef at 0x7664e610>
Traceback (most recent call last):
  File "/usr/lib/python3.9/logging/__init__.py", line 827, in _removeHandlerRef
  File "/usr/lib/python3.9/logging/__init__.py", line 221, in _acquireLock
  File "/usr/lib/python3.9/threading.py", line 156, in acquire
  File "/home/pi/.local/lib/python3.9/site-packages/gevent/thread.py", line 74, in get_ident
TypeError: 'NoneType' object is not callable_

amdgigabyte, 2024-05-07:
How did you solve this problem？I met this same log error

Closed 2023-04-25.

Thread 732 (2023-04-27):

After time, the server response time becomes slow. From 10 heartbeats per second to 1

fireduckfpv, 2023-04-27:
When the server has been powered on for a while (30 minutes to 10 hours) It goes from sending 10 heartbeats to 1 heartbeat pr second.

Setups I have tried on:
- Raspberry Pi 3B+, with 8 arduinos connected with SPI
- Raspberry Pi 3B+ with 4 arduinos connected with USB
They both run 4.0.0 Beta2, but the servers have had this bug for over a year so I do not believe it is a new bug. I really hoped this new version would fix it, but it has not.

In the beginning they both run completely fine, the python daemon / service is at 3-4 percent when I have a webpage open of the server and they send heartbeat 10 times a second, like clockwork. Nice response time on the webservice and everything works great.

But after a while, and it does not matter if it is a clean install or a database with 16 racers from a full day of racing, the response time drops from 10 heartbeats to 1 heartbeats and the python deamon / service is below 1 percent.

I have tried to reboot the server when this happends, but in order to get back to 10 heartbeats per second, I have to shut it down, and start it again. Then after an hour or so it goes bad again..

Any ideas on what to try to pinpoint what is going on?

( I use both Google Chrome / Inspect / Network and a custom websocket application to monitor the output from the server and measure heartbeats..)

HazardCreative, 2023-04-28:
I left two Pi 3B+ on for roughly 20 hours and it did not reproduce—both servers are sending heartbeats on the tenth.

What do you see for memory usage for the RH server?

Because you have to shut down the system instead of restarting the server to restore performance, I wonder if something is going on outside RH. Is something else on the pi taking up a lot of CPU or memory?

We should try to determine what other differences there are between your system and mine. Do you use the desktop? (My Pis are both installed with Lite / no desktop) How have you set it up?

fireduckfpv, 2023-04-28:
I use the standard Rasbian OS with no desktop. It is a clean install and I can see nothing else taking up any CPU.

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

fireduckfpv, 2023-04-28:
I am thinking that it might be an arduino issue, I am going to try to disconnect some of the arduinos and do some testing again.

fireduckfpv, 2023-04-28:
The odd thing is that the CPU useage actually goes down when it goes to 1 heartbeat pr second..

HazardCreative, 2023-04-28:
> I am thinking that it might be an arduino issue

Yes, that is definitely the next place to explore. The Pi that I left with the RH server running was STM32-based. Because your comments suggested the issue might be outside the server, I ran the second pi with no RH server running and just started it up to check the heartbeat.

I have already begin a new test with the server running on the Pi with Arduinos. If this replicates the issue.

The lower CPU load of the RH server does support the theory that the Arduinos are slowing down. We will see what my next test returns.

HazardCreative, 2023-04-29:
My Pi3B+ with 4 Arduinos is still going with no noticeable slowdown after just over 24hrs.

fireduckfpv, 2023-05-01:
I am currently testing with 8 active sensors and now there is no slowdown..  Maybe this is only an issue when one or more sensors are disabled..  I will do more testing.

HazardCreative, 2023-05-01:
Thanks for continuing to test. Let us know if you can isolate this.

fireduckfpv, 2023-05-01:
Finally caught it happen! :)

This time it was with 8 arduino sensors, 4 of them disabled. I will continue to try to make this happen with 8 enabled sensors.

Here is the database right after it happened.
[database_20230501_224700.zip](https://github.com/RotorHazard/RotorHazard/files/11368237/database_20230501_224700.zip)

Here is the server log as it happened!
Up to 22:39 (I think) it is 10hb pr second, after it still works but is only 1 hb pr second and the web response time is up to several seconds.

2023-05-01 19:13:47.327: __main__ [INFO] Staging new race, format: Fastest 3 Laps Qualifier
2023-05-01 19:13:47.332: __main__ [INFO] Racing heat 'Heat 1' round 2, pilots: Archaeopteryx, Bond1, Zenta, fireduck
2023-05-01 19:13:47.451: __main__ [INFO] Forcing race format from class setting: 'Fastest 3 Laps Qualifier' (7)
2023-05-01 19:13:47.474: __main__ [INFO] Current laps cleared
2023-05-01 19:13:47.562: __main__ [INFO] Lowering EnterAt/ExitAt values at start of race, amount=10%, duration=30 secs
2023-05-01 19:13:47.563: __main__ [INFO] For node 1 lowering EnterAt from 109 to 108 and ExitAt from 96 to 95
2023-05-01 19:13:47.683: __main__ [INFO] Not lowering EnterAt/ExitAt values for node 2 because EnterAt value (98) unchanged
2023-05-01 19:13:47.684: __main__ [INFO] For node 3 lowering EnterAt from 88 to 87 and ExitAt from 72 to 71
2023-05-01 19:13:47.748: __main__ [INFO] For node 4 lowering EnterAt from 90 to 89 and ExitAt from 74 to 73
2023-05-01 19:13:51.459: __main__ [INFO] Race started at 4629.127 (1682964831457)
2023-05-01 19:13:52.687: __main__ [INFO] Simulated lap: Node 1
2023-05-01 19:13:53.026: RHInterface [INFO] For node 1 restoring EnterAt to 109 and ExitAt to 96
2023-05-01 19:13:53.276: __main__ [INFO] Simulated lap: Node 2
2023-05-01 19:13:53.805: __main__ [INFO] Simulated lap: Node 3
2023-05-01 19:13:53.957: RHInterface [INFO] For node 3 restoring EnterAt to 88 and ExitAt to 72
2023-05-01 19:13:54.742: __main__ [INFO] Simulated lap: Node 4
2023-05-01 19:13:54.984: RHInterface [INFO] For node 4 restoring EnterAt to 90 and ExitAt to 74
2023-05-01 19:13:58.013: __main__ [INFO] Simulated lap: Node 1
2023-05-01 19:13:59.550: __main__ [INFO] Simulated lap: Node 2
2023-05-01 19:14:00.084: __main__ [INFO] Simulated lap: Node 3
2023-05-01 19:14:00.998: __main__ [INFO] Simulated lap: Node 4
2023-05-01 19:14:20.644: __main__ [INFO] Race stopped at 4658.313 (1682964860644), duration 29s
2023-05-01 19:14:21.785: __main__ [INFO] Current laps cleared
2023-05-01 19:14:53.988: __main__ [INFO] Race times adjusted for: Heat 2 Round 1 / Bond1
2023-05-01 19:14:54.112: __main__ [INFO] Updated calibration with best discovered values
2023-05-01 19:14:54.292: RHData [INFO] Building Class 1 results
2023-05-01 19:14:54.553: PageCache [INFO] T4692: Built results data in: 0.155529s
2023-05-01 19:14:57.780: __main__ [INFO] Race times adjusted for: Heat 2 Round 1 / Bond1
2023-05-01 19:14:57.930: __main__ [INFO] Updated calibration with best discovered values
2023-05-01 19:14:58.224: RHData [INFO] Building Class 1 results
2023-05-01 19:14:58.681: PageCache [INFO] T4696: Built results data in: 0.285885s
2023-05-01 19:25:17.130: BaseHardwareInterface [INFO] Interface: Read Error: [Errno 121] Remote I/O error
2023-05-01 19:38:02.616: BaseHardwareInterface [INFO] Interface: Read Error: [Errno 121] Remote I/O error
2023-05-01 20:12:41.462: BaseHardwareInterface [INFO] Interface: Read Error: [Errno 121] Remote I/O error
2023-05-01 21:17:20.490: BaseHardwareInterface [INFO] Interface: Read Error: [Errno 121] Remote I/O error
2023-05-01 21:32:33.514: BaseHardwareInterface [INFO] Interface: Read Error: [Errno 121] Remote I/O error
2023-05-01 22:33:38.775: BaseHardwareInterface [INFO] Interface: Read Error: [Errno 121] Remote I/O error
2023-05-01 22:34:25.215: BaseHardwareInterface [INFO] Interface: Read Error: [Errno 121] Remote I/O error
2023-05-01 22:39:49.441: BaseHardwareInterface [INFO] Interface: Read Error: [Errno 110] Connection timed out
2023-05-01 22:39:50.481: BaseHardwareInterface [INFO] Interface: Read Error: [Errno 110] Connection timed out
2023-05-01 22:39:50.482: BaseHardwareInterface [INFO] Interface: Retry (IOError) in read_block:  addr=10 cmd=14 size=8 retry=2 ts=16988.150980306
2023-05-01 22:39:51.521: BaseHardwareInterface [INFO] Interface: Read Error: [Errno 110] Connection timed out
2023-05-01 22:39:51.522: BaseHardwareInterface [INFO] Interface: Retry (IOError) in read_block:  addr=10 cmd=14 size=8 retry=3 ts=16989.190898216
2023-05-01 22:39:52.561: BaseHardwareInterface [INFO] Interface: Read Error: [Errno 110] Connection timed out
2023-05-01 22:39:52.562: BaseHardwareInterface [INFO] Interface: Retry (IOError) in read_block:  addr=10 cmd=14 size=8 retry=4 ts=16990.230967688
2023-05-01 22:39:53.601: BaseHardwareInterface [INFO] Interface: Read Error: [Errno 110] Connection timed out
2023-05-01 22:39:53.602: BaseHardwareInterface [INFO] Interface: Retry (IOError) limit reached in read_block:  addr=10 cmd=14 size=8 retry=5 ts=16991.270955806
2023-05-01 22:39:53.602: RHInterface [ERROR] Exception in RHInterface update_loop():
Traceback (most recent call last):
  File "../interface/RHInterface.py", line 211, in update_loop
    self.update()
  File "../interface/RHInterface.py", line 232, in update
    data.extend(node.read_block(self, READ_LAP_EXTREMUMS, 8))
TypeError: 'NoneType' object is not iterable
2023-05-01 22:39:55.681: BaseHardwareInterface [INFO] Interface: Read Error: [Errno 110] Connection timed out
2023-05-01 22:39:56.721: BaseHardwareInterface [INFO] Interface: Read Error: [Errno 110] Connection timed out
2023-05-01 22:39:56.722: BaseHardwareInterface [INFO] Interface: Retry (IOError) in read_block:  addr=8 cmd=13 size=8 retry=2 ts=16994.390972247
2023-05-01 22:39:57.761: BaseHardwareInterface [INFO] Interface: Read Error: [Errno 110] Connection timed out
2023-05-01 22:39:57.762: BaseHardwareInterface [INFO] Interface: Retry (IOError) in read_block:  addr=8 cmd=13 size=8 retry=3 ts=16995.430924482
2023-05-01 22:39:58.801: BaseHardwareInterface [INFO] Interface: Read Error: [Errno 110] Connection timed out
2023-05-01 22:39:58.802: BaseHardwareInterface [INFO] Interface: Retry (IOError) in read_block:  addr=8 cmd=13 size=8 retry=4 ts=16996.471002237
2023-05-01 22:39:59.841: BaseHardwareInterface [INFO] Interface: Read Error: [Errno 110] Connection timed out
2023-05-01 22:39:59.842: BaseHardwareInterface [INFO] Interface: Retry (IOError) limit reached in read_block:  addr=8 cmd=13 size=8 retry=5 ts=16997.510913588
2023-05-01 22:40:00.881: BaseHardwareInterface [INFO] Interface: Read Error: [Errno 110] Connection timed out
2023-05-01 22:40:01.921: BaseHardwareInterface [INFO] Interface: Read Error: [Errno 110] Connection timed out
2023-05-01 22:40:01.922: BaseHardwareInterface [INFO] Interface: Retry (IOError) in read_block:  addr=10 cmd=13 size=8 retry=2 ts=16999.590976393
2023-05-01 22:40:02.961: BaseHardwareInterface [INFO] Interface: Read Error: [Errno 110] Connection timed out
2023-05-01 22:40:02.962: BaseHardwareInterface [INFO] Interface: Retry (IOError) in read_block:  addr=10 cmd=13 size=8 retry=3 ts=17000.630993786
2023-05-01 22:40:04.001: BaseHardwareInterface [INFO] Interface: Read Error: [Errno 110] Connection timed out
2023-05-01 22:40:04.002: BaseHardwareInterface [INFO] Interface: Retry (IOError) in read_block:  addr=10 cmd=13 size=8 retry=4 ts=17001.670944096
2023-05-01 22:40:05.041: BaseHardwareInterface [INFO] Interface: Read Error: [Errno 110] Connection timed out
2023-05-01 22:40:05.042: BaseHardwareInterface [INFO] Interface: Retry (IOError) limit reached in read_block:  addr=10 cmd=13 size=8 retry=5 ts=17002.711052062
2023-05-01 22:40:10.321: BaseHardwareInterface [INFO] Interface: Read Error: [Errno 110] Connection timed out
2023-05-01 22:40:10.322: BaseHardwareInterface [INFO] Interface: Retry (IOError) limit reached in read_block:  addr=12 cmd=13 size=8 retry=5 ts=17007.990926384
2023-05-01 22:40:11.441: BaseHardwareInterface [INFO] Interface: Read Error: [Errno 110] Connection timed out
2023-05-01 22:40:12.481: BaseHardwareInterface [INFO] Interface: Read Error: [Errno 110] Connection timed out
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
fireduckfpv, 2023-05-02:
Just FYI, I still have not been able to reproduce the error when all sensors are enabled... Still trying though..

ethomas997, 2023-06-29:
Looks like this was a hardware problem, so closing this issue.  @fireduckfpv feel free to reopen if needed.

Closed 2023-06-29.

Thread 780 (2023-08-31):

Heat generator doesnt seem to work on second run

Aaronsss, 2023-08-31:
I used the heat generator to seed pilots into a qualifier but then tried to generate a second class for finals and it seems to crash the generator

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

log info:

RotorHazard v4.0.0-beta.4
Release: 4.0.0-beta.4 / Server API: 41 / Latest Node API: 35
Host machine: Raspberry Pi 3 Model B Rev 1.2
Host OS: Linux 6.1.21-v7+
Python version: 3.9.2
Host machine is 'LapTimer' at 192.168.68.15
Loaded plugin module rh_data_export_csv
Loaded plugin module rh_class_rank_heat_pos
Loaded plugin module rh_led_handler_strip
Loaded plugin module rh_points_by_position
Loaded plugin module rh_data_import_json
Loaded plugin module rh_led_handler_character
Loaded plugin module class_rank_best_pct_rounds
Loaded plugin module rh_led_handler_bitmap
Loaded plugin module rh_heatgenerator_standard
Loaded plugin module rh_led_handler_graph
Loaded plugin module rh_class_rank_best_x_rounds
Loaded plugin module class_rank_heat_points
Loaded plugin module rh_data_export_json
Loaded plugin module rh_actions_builtin
Loaded plugin module rh_heatgenerator_ladder
Loaded plugin module class_rank_best_x_laps
Loaded plugin module rh_class_rank_cumulative_points
Using configuration file 'config.json'
Using log file: logs/rh_20230831_234237.log
Loaded module i2c_helper
Loaded module i2c_node
Loaded module serial_node
Serial multi-node found at port '/dev/serial0', count=6, API_level=35, baudrate=921600, fw_version=1.1.4, fw_type=STM32F1, fw_timestamp: Apr 27 2021 21:17:24
Receiver modules found at slot positions: 1 2 3 4 5 6
Number of nodes found: 6
Loaded module bme280_sensor
Loaded module ina219_sensor
Loaded module linux_sensor
INA219 found at address 0x40 ('Battery')
Core temperature available
Set Profile to '1'
Updated calibration with best discovered values
VRx Control disabled: no registered controllers
Running http server at port 5000
Interface: Starting background thread
T4715: Built results data in: 0.315399s
Class 4 deleted
Generating heats via Balanced random fill
Exception via catchLogExceptionsWrapper
Traceback (most recent call last):
  File "/home/aaron/RotorHazard/src/server/RHUtils.py", line 182, in wrapper
    return func(*args, **kwargs)
  File "/home/aaron/RotorHazard/src/server/server.py", line 1670, in on_generate_heats_v2
    generate_result = RaceContext.heat_generate_manager.generate(generator, generate_args)
  File "/home/aaron/RotorHazard/src/server/HeatGenerator.py", line 60, in generate
    generated_heats = self._generators[generator_id].generate(self._rhapi, generate_args)
  File "/home/aaron/RotorHazard/src/server/HeatGenerator.py", line 161, in generate
    return self._generator(rhapi, generate_args)
  File "/home/aaron/RotorHazard/src/server/plugins/rh_heatgenerator_ladder/__init__.py", line 118, in generateBalancedHeats
    total_pilots = getTotalPilots(rhapi, generate_args)
  File "/home/aaron/RotorHazard/src/server/plugins/rh_heatgenerator_ladder/__init__.py", line 17, in getTotalPilots
    total_pilots = int(generate_args['total_pilots'])
TypeError: int() argument must be a string, a bytes-like object or a number, not 'NoneType'
Database heats reset
Database saved races reset
Switching to practice mode; races will not be saved until a heat is selected
T4791: Built results data in: 0.044320s
Database heats reset
Database race classes reset
Database saved races reset
Switching to practice mode; races will not be saved until a heat is selected
T4810: Built results data in: 0.027861s
Class added: Class <RaceClass 1>
Heat added: Heat 1
Heat 1 deleted
Class 1 deleted
Generating heats via Balanced random fill
Class added: Class <RaceClass 1>
Heat added: Heat 1
Heat added: Heat 2
Altered race class 1 to {'class_id': 1, 'class_name': 'Qualifier'}
Generating heats via Balanced random fill
Exception via catchLogExceptionsWrapper
Traceback (most recent call last):
  File "/home/aaron/RotorHazard/src/server/RHUtils.py", line 182, in wrapper
    return func(*args, **kwargs)
  File "/home/aaron/RotorHazard/src/server/server.py", line 1670, in on_generate_heats_v2
    generate_result = RaceContext.heat_generate_manager.generate(generator, generate_args)
  File "/home/aaron/RotorHazard/src/server/HeatGenerator.py", line 60, in generate
    generated_heats = self._generators[generator_id].generate(self._rhapi, generate_args)
  File "/home/aaron/RotorHazard/src/server/HeatGenerator.py", line 161, in generate
    return self._generator(rhapi, generate_args)
  File "/home/aaron/RotorHazard/src/server/plugins/rh_heatgenerator_ladder/__init__.py", line 118, in generateBalancedHeats
    total_pilots = getTotalPilots(rhapi, generate_args)
  File "/home/aaron/RotorHazard/src/server/plugins/rh_heatgenerator_ladder/__init__.py", line 17, in getTotalPilots
    total_pilots = int(generate_args['total_pilots'])
TypeError: int() argument must be a string, a bytes-like object or a number, not 'NoneType'

HazardCreative, 2023-08-31:
This looks like something that was fixed after the beta release. Please update to the latest dev code and see if it persists.

HazardCreative, 2023-10-08:
Closing after no response; please re-raise if the issue occurs after an update.

Closed 2023-10-08.

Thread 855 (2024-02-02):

New issue on main - only when connected to NH PCB

szafranski, 2024-02-02:
Hi, just got this on the fresh install:

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

ethomas997, 2024-02-02:
Please post full log zip here

szafranski, 2024-02-03:
Same on newest beta. How can I obtain that log?

szafranski, 2024-02-03:
I think this is it:
[logs.zip](https://github.com/RotorHazard/RotorHazard/files/14148722/logs.zip)

szafranski, 2024-02-03:
I have some VERY interesting info - this only shows when connected to NuclearHazard PCB...

ethomas997, 2024-02-03:
> I think this is it: [logs.zip](https://github.com/RotorHazard/RotorHazard/files/14148722/logs.zip)

That zip contains no files.  See here for generating logs zip file:  https://github.com/RotorHazard/RotorHazard/blob/main/doc/Software%20Setup.md#logging

szafranski, 2024-02-04:
That should be it - sorry, used wrong zip command
[logs.zip](https://github.com/RotorHazard/RotorHazard/files/14155130/logs.zip)

szafranski, 2024-02-04:
I don't get it everytime, but most times and only when NH PCB is used

ethomas997, 2024-02-04:
Please post the 'config.json' file that was in use when the error(s) happened.

(In general it's better if you generate a ".zip" file using the "Download Logs" button (in Settings | System) and post it because this gives us more information.)

ethomas997, 2024-02-04:
@szafranski  Please also post the output of "pip list".

I'm testing on the same hardware & software setup that I see in your logs and I am not able to reproduce those errors; this is my setup:

```
2024-02-04 15:02:09.282: __main__ [INFO] Release: 4.1.0-beta.1 / Server API: 43 / Latest Node API: 35
2024-02-04 15:02:09.283: __main__ [DEBUG] Program started at 1707076928179, time=2024-02-04 15:02:08.179
2024-02-04 15:02:09.283: RHUtils [INFO] Host machine: Raspberry Pi 5 Model B Rev 1.0
2024-02-04 15:02:09.302: RHUtils [INFO] Host OS: Debian GNU/Linux 12 (bookworm) 64-bit (Linux 6.1.0-rpi8-rpi-2712)
2024-02-04 15:02:09.302: RHUtils [INFO] Python version: 3.11.2
2024-02-04 15:02:09.360: RHUtils [INFO] S32_BPill board detected
```

szafranski, 2024-02-11:
I downloaded logs via server gui. Attached
[rh_logs_20240211_015551.zip](https://github.com/RotorHazard/RotorHazard/files/14230940/rh_logs_20240211_015551.zip)

ethomas997, 2024-02-11:
Thanks for posting the logs-zip file.  When using the Pi 5, this line should not be present in the boot-config file:
`dtoverlay=gpio-shutdown,gpio_pin=19,debounce=2500`

Your boot-config file seems rather messy, with multiple repeated items.  See the current Software Setup for the recommended modifications to the boot-config file.  I think the RH Install Manager should adhere to those modifications.  Let me know if you think any settings should be different from the ones specified in the Software Setup doc.

Please see if starting from the default version of the boot-config file and modifying it as specified in the Software Settings clears up the GPIO errors.

szafranski, 2024-02-11:
Ok, so:

1. removed line: dtoverlay=gpio-shutdown,gpio_pin=19,debounce=2500
resolved the issue
but in your doc you have:

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

I don't see the info that in case of Pi 5 it should not be applied

2. As for my config file:
it only has what it should but with [<pi_version>]
and it causes those commands to be only applied when given pi version is found

3. Do you see any "unnecessary" code in my config file?

Thanks!

ethomas997, 2024-02-13:
That's the old doc; see the current on the main branch:  https://github.com/RotorHazard/RotorHazard/blob/main/doc/Software%20Setup.md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

In your config file you have several instances of the same line duplicated multiple times (for instance "dtparam=act_led_trigger=heartbeat", and several others).

Also, I think "dtparam=i2c_baudrate=75000" should be present for all versions of the Pi.

szafranski, 2024-02-13:
Ok, I surely used the code from the stable branch so that's explained, thank you.
As for multiple lines - I did some testing so that's probably why. Actually it doesn't change anything but thanks for pointing that out.

As for dtparam=i2c_baudrate=75000 - as far as I know it was only needed on Pi 3. I never used this on Pi 4 or 5 (and many other people as well) and everything seems to work ok. Are you sure it is needed?

ethomas997, 2024-02-14:
As I understand it the "dtparam=i2c_baudrate=75000" setting will affect the speed of the I2C bus when using Arduino/I2C nodes, regardless of the type of Pi used.

szafranski, 2024-02-14:
But is that necessary to work? I tested this on pi 4 with Arduino nodes and it doesn't seems to make any difference.

ethomas997, 2024-02-22:
We'd have to research what the default value is to really know.  But I'd say that unless there's good reason for removing it, the line should be present.  I'm going to close this issue, but feel free to reopen or make a new one if needed.

Closed 2024-02-22.

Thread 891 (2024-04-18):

NuclearHazard Beeper not working in Beta or Main when power button is pressed

Redalin, 2024-04-18:
I have a Nuclearhazard PCB with a Raspberry Pi 4 and 4x RX5808 receivers.

**Describe the bug**
When Running the Stable branch of RH the NuclearHazard works great as expected.
To power it down using the hardware power button on the PCB it beeps when the button is pressed, and if held down for 2.5 seconds it shuts down the Pi while beeping, and does a long beep when shutdown is complete.

After an update to the Beta branch the buzzer no longer beeps when the power button is pressed. If held down the Pi still shuts down but does not run the beep cycle. Stays silent the whole time and gives no indication of shutdown status.
The Beeper DOES still beep on startup (2 when power applied, 2 when startup complete and 1 when the first connection is made).

Updating to the Main branch also exhibits the same behaviour.

Rolling back to the Stable branch the beeper starts working again

**To Reproduce**
Steps to reproduce the behavior:
1. In RHIM, go to Rotorhazard manager - update the origin to Beta
2. update the existing configuration
3. clear the old installation
4. reboot
5. Pi will reboot and beep when ready
6. Press the power button and hear no beeps.
7. Repeat steps 1-5 but change Origin to Stable
8. Press the power button and hear beeps.

ethomas997, 2024-04-26:
@Redalin Thanks for the report.  If possible, could you generate a ".zip" file using the "Download Logs" button (in Settings | System), generating one when it's working and one when it's not working, and post them here?

Redalin, 2024-04-30:
Thanks @ethomas997 I have attached them. Although I think i see the error you are looking for:

```
2024-05-01 11:40:50.891: __main__ [ERROR] Exception error in ButtonInputHandler setup
Traceback (most recent call last):
  File "/usr/lib/python3/dist-packages/gpiozero/pins/pi.py", line 408, in pin
    pin = self.pins[info]
          ~~~~~~~~~^^^^^^
KeyError: PinInfo(number=35, name='GPIO19', names=frozenset({'J8:35', 19, '19', 'BCM19', 'WPI24', 'GPIO19', 'BOARD35'}), pull='', row=18, col=1, interfaces=frozenset({'', 'dpi', 'gpio', 'pcm', 'spi', 'pwm'}))

During handling of the above exception, another exception occurred:

Traceback (most recent call last):
  File "/home/chris/RotorHazard/src/server/util/ButtonInputHandler.py", line 28, in __init__
    RH_GPIO.setup(gpioPinNum, RH_GPIO.IN, pull_up_down=RH_GPIO.PUD_UP)
  File "/home/chris/RotorHazard/src/server/util/RH_GPIO.py", line 90, in setup
    Input_devices_dict[channel] = gpiozero.InputDevice(channel, \
                                  ^^^^^^^^^^^^^^^^^^^^^^^^^^^^^^^
  File "/usr/lib/python3/dist-packages/gpiozero/devices.py", line 103, in __call__
    self = super().__call__(*args, **kwargs)
           ^^^^^^^^^^^^^^^^^^^^^^^^^^^^^^^^^
  File "/usr/lib/python3/dist-packages/gpiozero/input_devices.py", line 79, in __init__
    super().__init__(pin, pin_factory=pin_factory)
  File "/usr/lib/python3/dist-packages/gpiozero/devices.py", line 549, in __init__
    pin = self.pin_factory.pin(pin)
          ^^^^^^^^^^^^^^^^^^^^^^^^^
  File "/usr/lib/python3/dist-packages/gpiozero/pins/pi.py", line 410, in pin
    pin = self.pin_class(self, info)
          ^^^^^^^^^^^^^^^^^^^^^^^^^^
  File "/usr/lib/python3/dist-packages/gpiozero/pins/lgpio.py", line 126, in __init__
    lgpio.gpio_claim_input(
  File "/usr/lib/python3/dist-packages/lgpio.py", line 755, in gpio_claim_input
    return _u2i(_lgpio._gpio_claim_input(handle&0xffff, lFlags, gpio))
           ^^^^^^^^^^^^^^^^^^^^^^^^^^^^^^^^^^^^^^^^^^^^^^^^^^^^^^^^^^^
  File "/usr/lib/python3/dist-packages/lgpio.py", line 458, in _u2i
    raise error(error_text(v))
lgpio.error: 'GPIO busy'
```

Beta
[rh_logs_20240501_114453.zip](https://github.com/RotorHazard/RotorHazard/files/15172260/rh_logs_20240501_114453.zip)

Stable
[rh_logs_20240501_111351.zip](https://github.com/RotorHazard/RotorHazard/files/15172262/rh_logs_20240501_111351.zip)

Redalin, 2024-05-01:
@ethomas997 I just tested it on the Main branch. (v4.1.0-dev.11) and the beeper is working again.
Well done :)

ethomas997, 2024-05-01:
Thanks for posting the info; great to hear it's working now!

Closed 2024-05-01.

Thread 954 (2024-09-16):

Arduino nano 'L' led stuck on and not working

papage, 2024-09-16:
Hi all,

I am running rotorhazard v4.1.1 with a DIY hardware setup of four aduino nanos with four rx5808 VRXs (the delta5 setup).
Rotorhazard recognises the four arduinos but when i go to Rotorhazard's calibration screen, some arduinos don't work and Rotorhazard can't get RSSI readings from them.
When an arduino is not working, you can tell because the 'L' led stays lit (on), while on working arduinos you can see the 'L' led flashing as Rotorhazard reads rssi values and displays them.
It is not an issue with the wirings or the arduinos or the rx5808s because I have done testing in order to find what is not working and i have failed to find the cause of this, which seems to be random but very frequent. The rotorhazard's log does not say anything. It just reports the arduinos found it seems to be able to talk to them through the i2c.

So, the question is what does it mean when the 'L' led on an arduino remains 'on'? Is there a debug option i Rotorhazard to help me debug the issue?

Thanx

HazardCreative, 2024-09-17:
There is no circumstance in which RotorHazard intentionally sets the status LED to solid. This suggests instead that the Arduino has crashed/frozen. That could be caused by various hardware failures including insufficient power or a bad chip. You're saying it happens frequently. If it's always the same Arduino, replace it. if it's different Arduinos, check the board or power supply.

HazardCreative, 2025-05-23:
No further information or repro case provided; closing. Please reopen if new information is available.

Closed 2025-05-23.

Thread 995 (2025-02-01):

GUI says the node is working properly, but the RX5808 is not changing frequency (SPI mod is done)

wolfboomzoom, 2025-02-01:
I built a Rotorhazard STM32 node.

I used the Arduino utility app linked to at   #[654](https://github.com/RotorHazard/RotorHazard/issues/654#issuecomment-1087952520) to confirm the SPI mod has been done on all of my RX5808 modules. I got good readouts from all of my RX5808 modules, the app showed the data in the registers, and the SPI bus is working. All of my RX5808 modules are good, and the app confirmed the SPI mod has been done.

But my Rotorhazard still acts as if the SPI mod has not been done.

Additional details

1. When I set my RX5808 modules to a frequency other than R1, my RX5808 modules do not actually change to detect that frequency.
2. I set both the RX5808 module and a drone to R8. I did not see a change in the RRSI value.
3. I changed the drone to R1, leaving the RX5808 module at R8. I got a spike in the RSSI value.
4. I left the drone in R1 and changed the RX5808 module to R1. The RSSI value remained the same as for test 2.
5. I left my drone in R1 and changed my RX5808 module to R8 again. That dropped the RRSI value back down to the value for test 1.
6. Changing my drone back to R8 and leaving my RX5808 module in R8 (test 1’s conditions) did not impact the RSSI value from test 4 (which matches test 1).

I don’t know what to do to get the RX5808 modules to actually change frequency.

Thanks for the help.

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

[rh_logs_20250201_160353.zip](https://github.com/user-attachments/files/18630603/rh_logs_20250201_160353.zip)

ethomas997, 2025-02-03:
In your picture it looks like you have multiple RX5808s plugged in, so if you've been testing that way I'd suggest trying to work with one installed at a time.  You could try setting up one as a USB Node -- if it works that way, then the issue is probably with your S32_BPill board.  You'll want to check solder joints, continuity, etc.

See here for USB Node:  https://github.com/RotorHazard/RotorHazard/blob/main/doc/USB%20Nodes.md

wolfboomzoom, 2025-02-15:
> In your picture it looks like you have multiple RX5808s plugged in, so if you've been testing that way I'd suggest trying to work with one installed at a time. You could try setting up one as a USB Node -- if it works that way, then the issue is probably with your S32_BPill board. You'll want to check solder joints, continuity, etc.
>
> See here for USB Node: https://github.com/RotorHazard/RotorHazard/blob/main/doc/USB%20Nodes.md

Closed 2025-02-15.

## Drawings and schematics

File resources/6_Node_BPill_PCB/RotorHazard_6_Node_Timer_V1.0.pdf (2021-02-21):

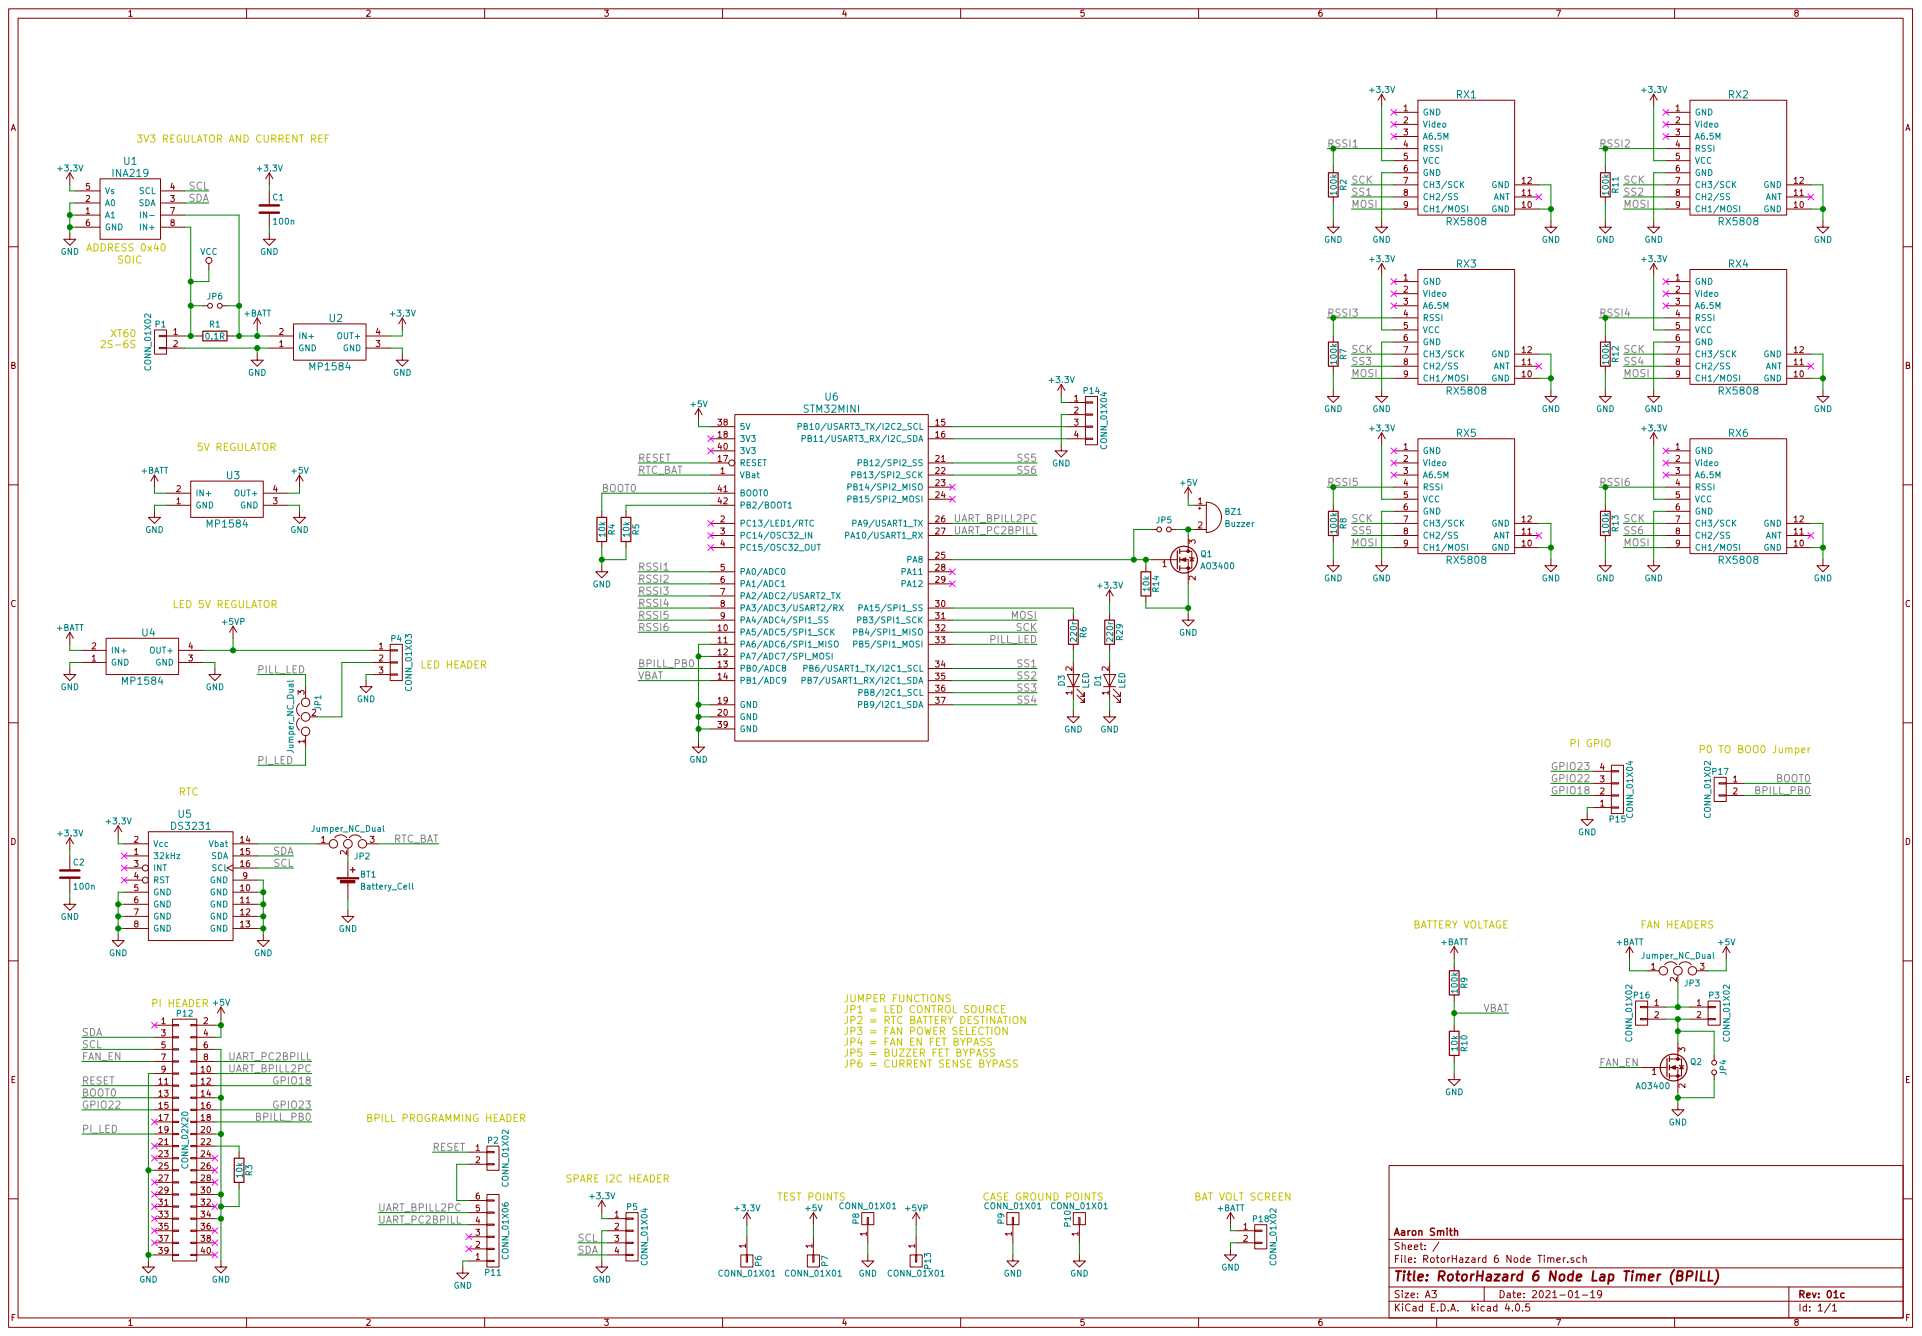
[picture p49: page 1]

3V3 REGULATOR AND CURRENT REF
0.1R SCL

39 P12CONN_02X20 GND 15 | GND SCL

JP1 = LED CONTROL SOURCE
JP2 = RTC BATTERY DESTINATION
JP3 = FAN POWER SELECTION
JP4 = FAN EN FET BYPASS
JP5 = BUZZER FET BYPASS
JP6 = CURRENT SENSE BYPASS

17 | | 18 | BPILL_PB0

2 P18 CONN_01X02+BATT GND BAT VOLT SCREEN

Id: 1/1 Title: RotorHazard 6 Node Lap Timer (BPILL) File: RotorHazard 6 Node Timer.sch Sheet: / Aaron Smith

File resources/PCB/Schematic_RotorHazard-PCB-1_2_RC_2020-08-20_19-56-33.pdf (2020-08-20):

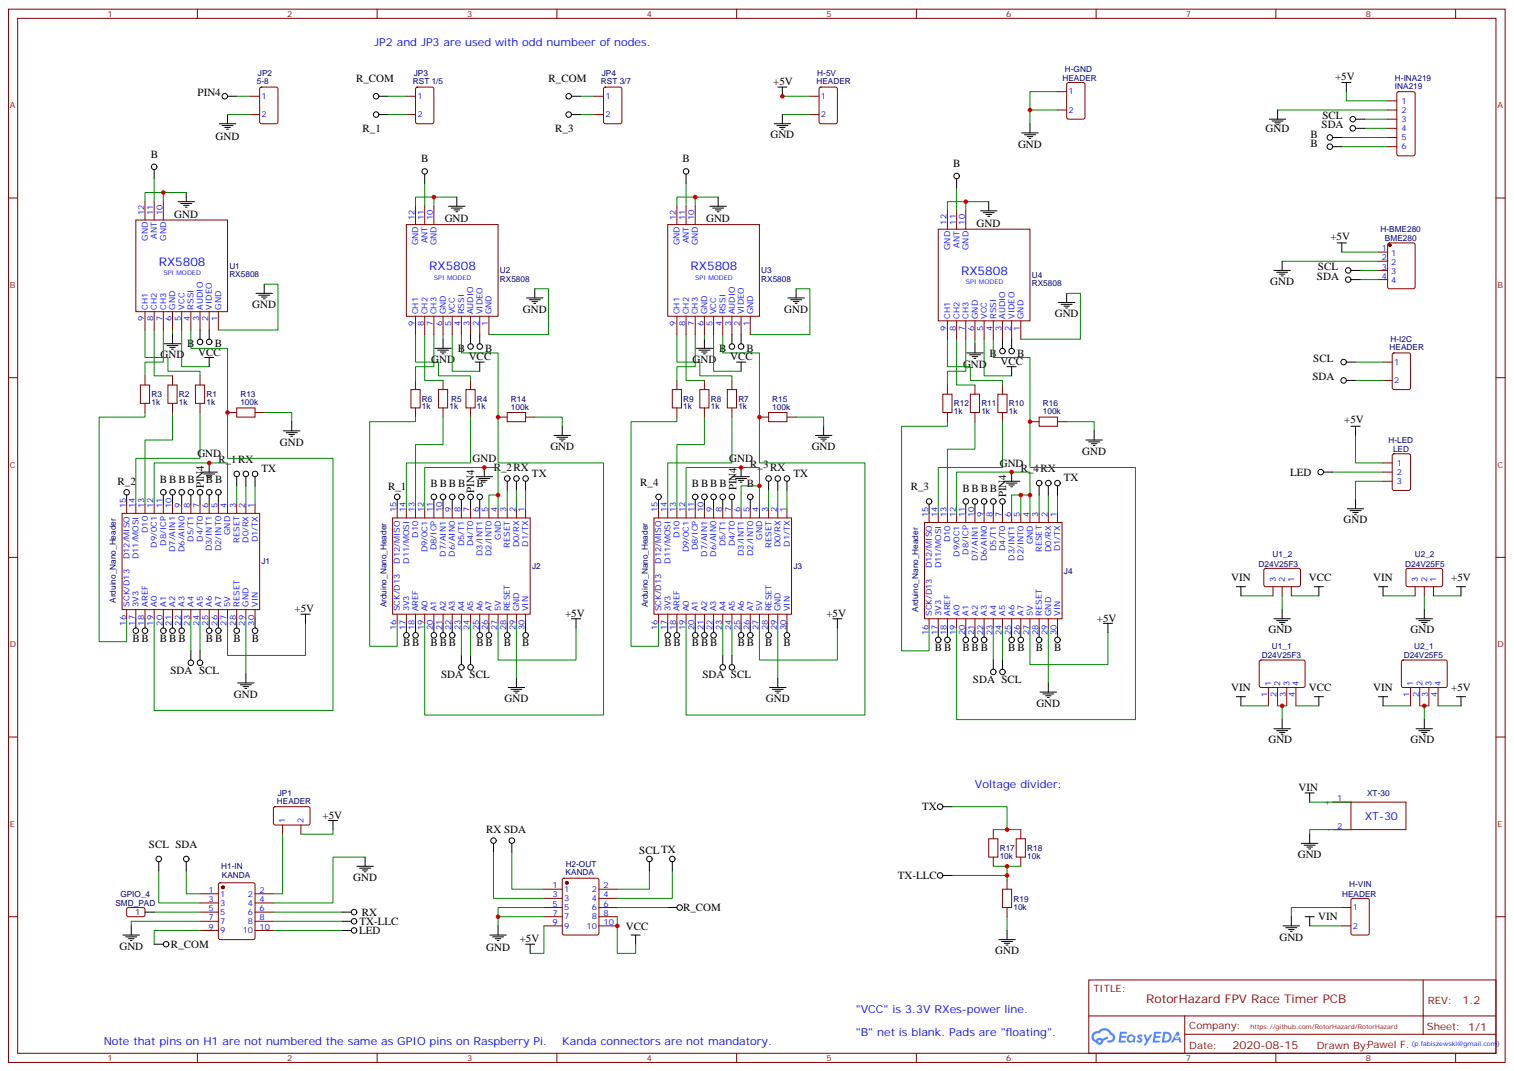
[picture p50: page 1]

JP2 and JP3 are used with odd numbeer of nodes.

SDA SCL

"VCC" is 3.3V RXes-power line.
"B" net is blank. Pads are "floating".

Company: https://github.com/RotorHazard/RotorHazard

Note that pins on H1 are not numbered the same as GPIO pins on Raspberry Pi. Kanda connectors are not mandatory.

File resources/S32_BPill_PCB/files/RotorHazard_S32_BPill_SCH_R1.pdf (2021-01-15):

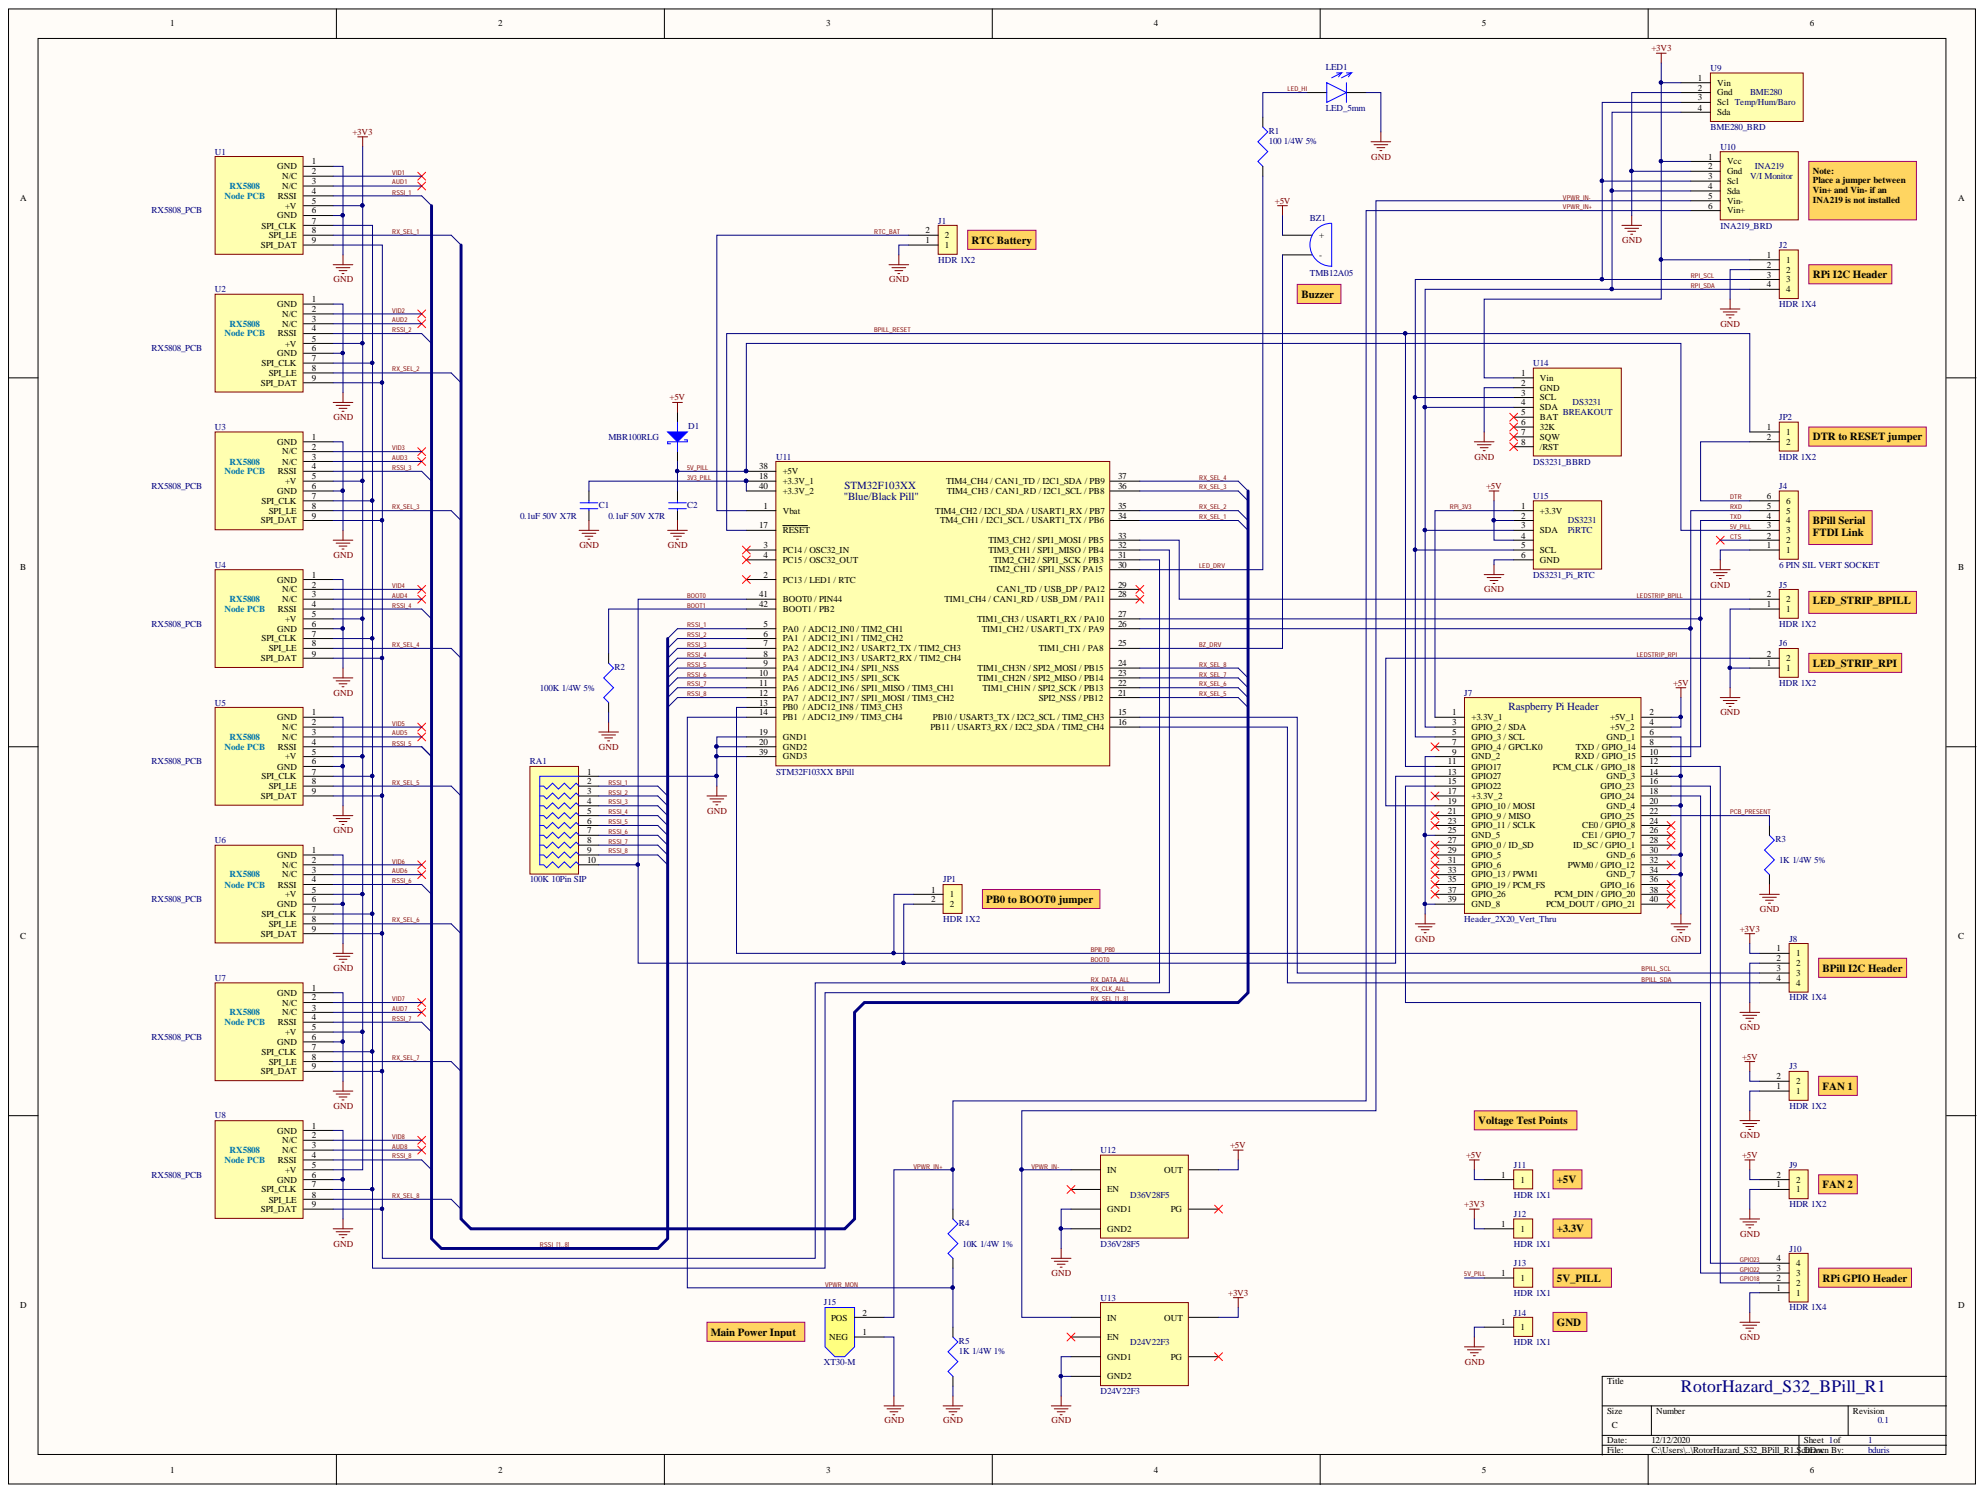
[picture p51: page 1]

RPi I2C Header Note: Place a jumper betw

+ 5 V + 3 . 3 V _ 1 STM32F103XX "Blue/Black Pill" + 3 . 3 V _2 | T M TIM / TIM 2_CH / TIM 2_CH TIM 3 _CH TIM 3 _CH PB1 0 | 4_CH 4 / CA N 1 4_CH 3 / CA N 1 4_CH 2 / I2C1 _ S D 4_CH 1 / I2C1 _ SCL TIM 3 _CH TIM 3 _CH TIM 2_CH TIM 2_CH 1 _CH 4 / CA N 1 TIM 1 _CH 3 TIM 1 _CH 3 4 TIM 1 _CH 3 TIM 1 _CH 2 1 TIM 1 _CH 2 / U S ART 3 _T X / I2C2 U S ART 3 _RX / I2C2 | _T D / I2C1 _ S D A / PB9 _RD / I2C1 _ SCL / PB8 A / U S ART 1 _RX / PB7 / U S ART 1 _T X / PB6 2 / S PI1 _M O SI / PB5 1 / S PI1 _MIS O / PB4 2 / S PI1 _ SCK / PB3 1 / S PI1 _N S S / P A 1 5 _RD / U SB_D M / P A 1 1 / U S ART 1 _RX / P A 1 0 2 / U S ART 1 _T X / P A 9 TIM 1 _CH 1 / P A 8 N / S PI2 _M O SI / PB1 5 N / S PI2 _MIS O / PB1 4 1 N / S PI2 _ SCK / PB1 3 S PI2 _N S S / PB1 2 _ SCL / TIM 2_CH 3 _ S D A / TIM 2_CH 4

BOOT 0 | 1 8 4 0 1

BOOT 1 | 4 2 | 2 7 | 1

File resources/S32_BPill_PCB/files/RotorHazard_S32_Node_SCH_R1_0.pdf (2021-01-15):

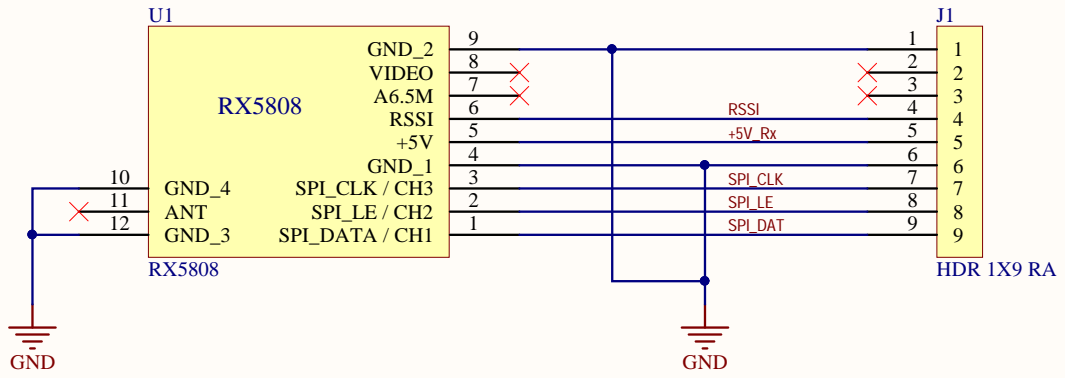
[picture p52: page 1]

8 7 | 2 3 4 RSSI

4 +5V 5 RSSI 6 | +5V_Rx 5

3 | 7 SPI_CLK

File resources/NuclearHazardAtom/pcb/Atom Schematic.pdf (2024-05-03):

## Pi: 1.8A Fans (2x 40mm): 0.3A

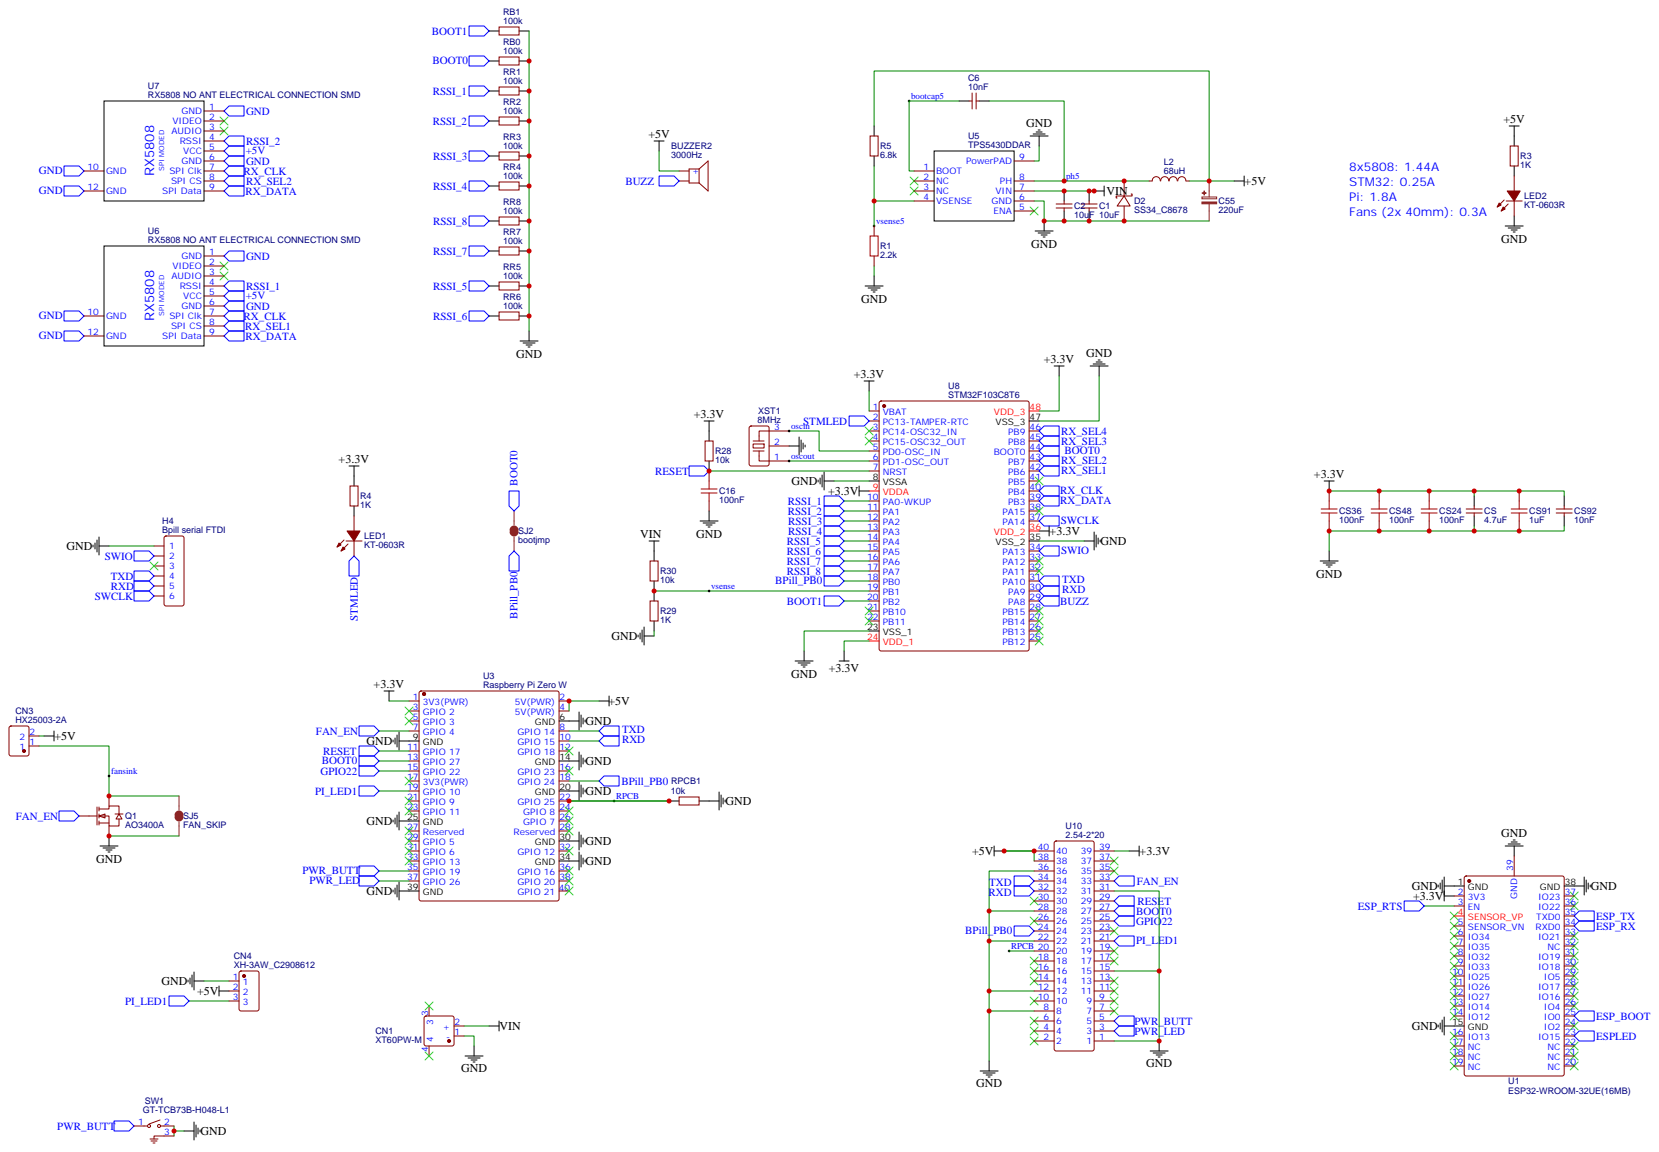
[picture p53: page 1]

RX5808 NO ANT ELECTRICAL CONNECTION SMD

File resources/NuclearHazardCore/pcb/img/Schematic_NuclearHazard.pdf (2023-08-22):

## 3A max for each VReg + Inductor

## Pi: 1.8A

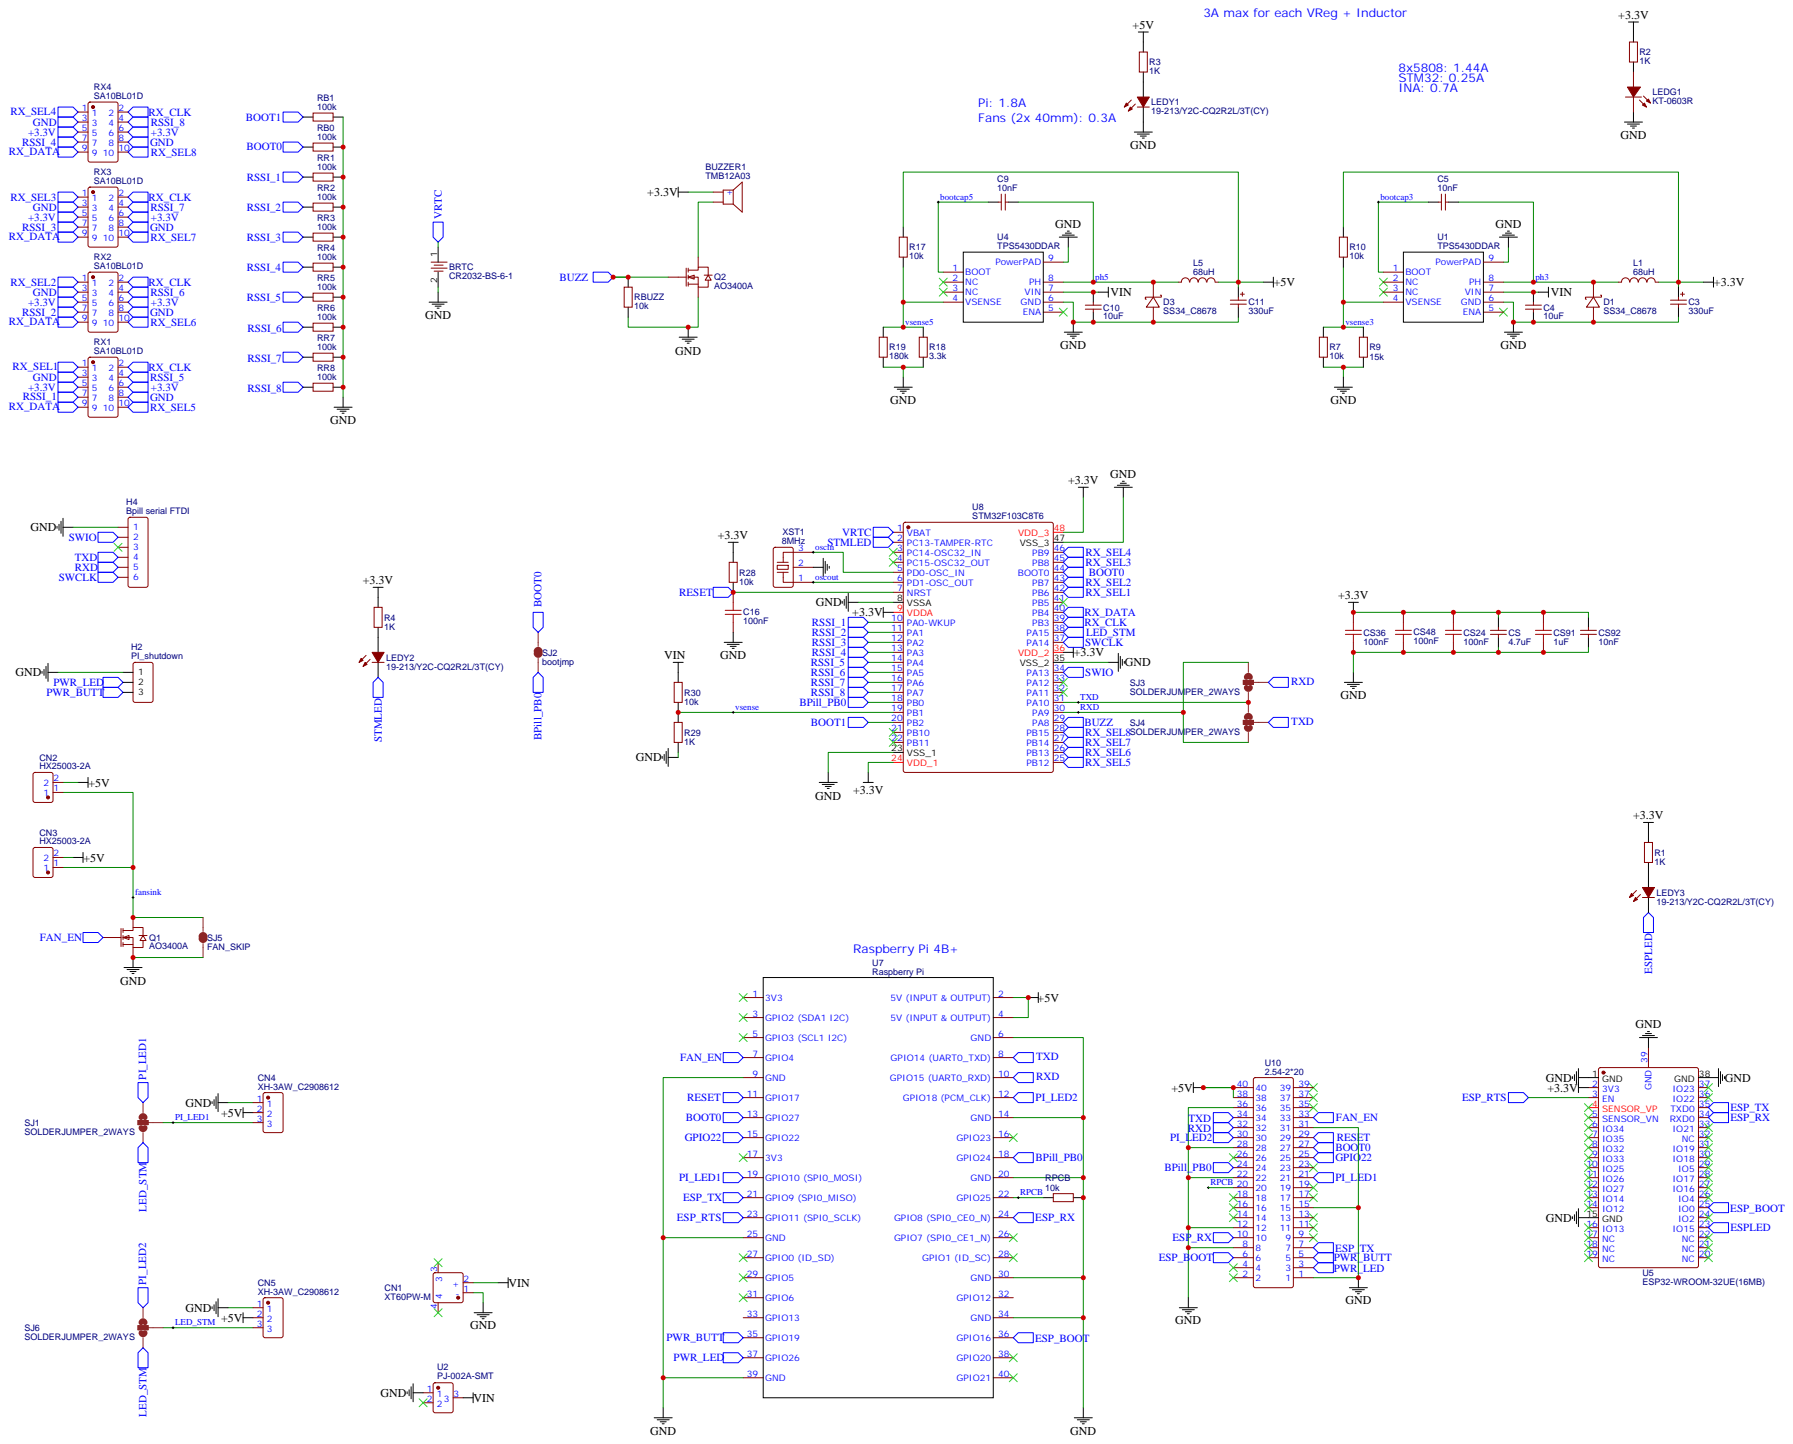
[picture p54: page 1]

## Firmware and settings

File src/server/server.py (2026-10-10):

'''RotorHazard server script'''
RELEASE_VERSION = "4.5.1-dev.4" # Public release version code
SERVER_API = 49 # Server API version
NODE_API_SUPPORTED = 18 # Minimum supported node version
NODE_API_BEST = 36 # Most recent node API
JSON_API = 3 # JSON API version
MIN_PYTHON_MAJOR_VERSION = 3 # minimum python version (3.10)
MIN_PYTHON_MINOR_VERSION = 10

# command-line arguments:
CMDARG_VERSION_LONG_STR = '--version'    # show program version and exit
CMDARG_VERSION_SHORT_STR = '-v'          # show program version and exit
CMDARG_ZIP_LOGS_STR = '--ziplogs'        # create logs .zip file
CMDARG_JUMP_TO_BL_STR = '--jumptobl'     # send jump-to-bootloader command to node
CMDARG_FLASH_BPILL_STR = '--flashbpill'  # flash firmware onto S32_BPill processor
CMDARG_VIEW_DB_STR = '--viewdb'          # load and view given database file
CMDARG_LAUNCH_B_STR = '--launchb'        # launch browser on local computer
CMDARG_DATA_DIR = '--data'               # use given dir as data location
CMDARG_MIN_MOCKS = '--mock-nodes'        # add at least this many mock nodes

# This must be the first import for the time being. It is
# necessary to set up logging *before* anything else
# because there is a lot of code run through imports, and
# we would miss messages otherwise.
import logging
import log
from datetime import datetime
from time import monotonic
import RHTimeFns

log.early_stage_setup()
logger = logging.getLogger(__name__)

EPOCH_START = RHTimeFns.getEpochStartTime()

_prog_start_epoch1 = (RHTimeFns.getUtcDateTimeNow() - EPOCH_START).total_seconds()

# program start time (in time.monotonic seconds)
_program_start_mtonic = monotonic()

# do average of before and after to exact timing match between _program_start_epoch_time and _program_start_mtonic
_prog_start_epoch2 = (RHTimeFns.getUtcDateTimeNow() - EPOCH_START).total_seconds()

# program-start time, in milliseconds since 1970-01-01
_program_start_epoch_time = int((_prog_start_epoch1 + _prog_start_epoch2) * 500.0 + 0.5)   # *1000/2.0

logger.info('RotorHazard v{0}'.format(RELEASE_VERSION))

# Normal importing resumes here
import RHUtils  # need to import this early to get RH_GPIO initialized before gevent, etc
from RHUtils import catchLogExceptionsWrapper

import gevent.monkey
gevent.monkey.patch_all()

import io
import os
import sys
import base64
import subprocess
import importlib
# import copy
import functools
import signal
import werkzeug
import urllib3

from flask import Flask, send_from_directory, request, make_response, Response, templating, redirect, abort, copy_current_request_context
from flask.blueprints import Blueprint
from flask_socketio import SocketIO, emit

PROGRAM_DIR = os.path.dirname(os.path.realpath(__file__))

# determine data location
DATA_DIR = None
CONFIG_FILE_NAME = 'config.json'
CFG_BKP_DIR_NAME = 'cfg_bkp'
implicit_program_dir_flag = False

# 1: --data command-line arg
if __name__ == '__main__' and len(sys.argv) > 1 and CMDARG_DATA_DIR in sys.argv:
    data_dir_arg_idx = sys.argv.index(CMDARG_DATA_DIR) + 1
    if data_dir_arg_idx < len(sys.argv):
        data_path = os.path.expanduser(sys.argv[data_dir_arg_idx])  # expand '~' to user-home directory
        if os.path.exists(data_path):
            DATA_DIR = data_path
        else:
            print("Unable to find given data location: {0}".format(sys.argv[data_dir_arg_idx]))
            sys.exit(1)
    else:
        print("Usage: python server.py --data {0}".format(CMDARG_DATA_DIR))
        sys.exit(1)

# 2: RH_DATA_DIR environment variable
if not DATA_DIR:
    data_path = os.environ.get('RH_DATA_DIR')
    if data_path:
        data_path = os.path.expanduser(data_path)
        if os.path.exists(data_path):
            DATA_DIR = data_path
        else:
            print("Unable to find data location given by RH_DATA_DIR: {0}".format(data_path))
            sys.exit(1)

# 3: datapath.ini
if not DATA_DIR:
    try:
        datapath_ini_path_str = os.path.join(PROGRAM_DIR, 'datapath.ini')
        with open(datapath_ini_path_str, 'r') as f:
            data_path = os.path.expanduser(f.readline().strip())  # expand '~' to user-home directory
            if len(data_path) > 0:
                if os.path.exists(data_path):
                    DATA_DIR = data_path
                else:
                    print('"{}" file points to an invalid system location: "{}"'.\
                          format(datapath_ini_path_str, data_path))
                    sys.exit(1)
    except IOError:
        # missing file is valid
        pass
    except Exception as ex:
        print('Error processing "{}" file: {}'.format(datapath_ini_path_str, ex))
        sys.exit(1)

# 4: ~/rh-data, if exists
if not DATA_DIR:
    data_path = os.path.expanduser("~/rh-data")
    if os.path.isdir(data_path):
        DATA_DIR = data_path

# 5: Implicit run from PROGRAM_DIR
# If "config.json" exists in PROGRAM_DIR, use PROGRAM_DIR as data dir and prompt user with a choice:
if not DATA_DIR:
    if os.path.exists(os.path.join(PROGRAM_DIR, CONFIG_FILE_NAME)):
        DATA_DIR = PROGRAM_DIR
        implicit_program_dir_flag = True

# 6: If CWD contains config use CWD
if not DATA_DIR:
    if os.path.exists(os.path.join(os.getcwd(), CONFIG_FILE_NAME)):
        DATA_DIR = os.getcwd()

# 7: ~/rh-data, creating as needed
if not DATA_DIR:
    try:
        os.makedirs(os.path.expanduser("~/rh-data"), exist_ok=True)
    except OSError:
        print("Unable to access or create ~/rh-data and no alternate path specified")
        sys.exit(1)
    DATA_DIR = os.path.expanduser("~/rh-data")

os.chdir(DATA_DIR)
sys.path.insert(0, DATA_DIR)

DB_FILE_NAME = 'database.db'
DB_BKP_DIR_NAME = 'db_bkp'
_DB_URI = 'sqlite:///' + os.path.join(DATA_DIR, DB_FILE_NAME)

sys.path.append(PROGRAM_DIR + '/util')

APP = Flask(__name__, template_folder=PROGRAM_DIR+'/templates', static_folder=PROGRAM_DIR+'/static', static_url_path='/static')
APP.app_context().push()

import FlaskAppObj
FlaskAppObj.set_flask_app(APP)

import Database
Database.initialize(_DB_URI)

import socket
import random
import string
import json
from pathlib import Path

RHUtils.checkPythonVersion(MIN_PYTHON_MAJOR_VERSION, MIN_PYTHON_MINOR_VERSION)

import Results
import Language
import json_endpoints
import EventActions
import RaceContext
import RHData
import RHUI
import AdminAuth
import calibration
import heat_automation
import RHAPI
from ClusterNodeSet import SecondaryNode, ClusterNodeSet, restore_secondary_passwords, mask_secondary_passwords
import PageCache
from util.ButtonInputHandler import ButtonInputHandler
import util.stm32loader as stm32loader
from interface_mapper import InterfaceMapper, InterfaceType

# Events manager
from eventmanager import Evt, EventManager

# Filter manager
from filtermanager import FilterManager

# Plugin manager
import requests
from util.plugin_installation import PluginInstallationManager

# LED imports
from led_event_manager import LEDEventManager, NoLEDManager, ClusterLEDManager, LEDEvent, Color, ColorVal, ColorPattern

sys.path.append(PROGRAM_DIR + '/../interface')
sys.path.append('/home/pi/RotorHazard/src/interface')  # Needed to run on startup

from Plugins import search_modules  #pylint: disable=import-error
from Sensors import Sensors  #pylint: disable=import-error
import RHRace
from RHRace import WinCondition, RaceStatus
from data_export import DataExportManager
from data_import import DataImportManager
from VRxControl import VRxControlManager
from HeatGenerator import HeatGeneratorManager

# Create shared context
RaceContext = RaceContext.RaceContext(CONFIG_FILE_NAME, CFG_BKP_DIR_NAME)
RHAPI = RHAPI.RHAPI(RaceContext)

RaceContext.serverstate.server_instance_token = random.random()
RaceContext.serverstate.program_start_epoch_time = _program_start_epoch_time
RaceContext.serverstate.program_start_mtonic = _program_start_mtonic
RaceContext.serverstate.mtonic_to_epoch_millis_offset = RaceContext.serverstate.program_start_epoch_time - \
                                                        1000.0*RaceContext.serverstate.program_start_mtonic
RaceContext.serverstate.data_dir = DATA_DIR
RaceContext.serverstate.program_dir = PROGRAM_DIR
RaceContext.serverstate.implicit_program_dir_flag = implicit_program_dir_flag
RaceContext.serverstate.do_rhdata_migrate_flag = False
RaceContext.serverstate.rhapi_version = ".".join(map(str, (RHAPI.API_VERSION_MAJOR, RHAPI.API_VERSION_MINOR)))

RaceContext.interface = InterfaceMapper(RaceContext)
Events = EventManager(RaceContext)
RaceContext.events = Events
Filters = FilterManager(RHAPI)
RaceContext.filters = Filters
EventActionsObj = None
LedStripObj = None
Use_imdtabler_jar_flag = False  # set True if IMDTabler.jar is available
Server_ipaddress_str = None
ShutdownButtonInputHandler = None
Server_secondary_mode = None
HardwareHelpers = {}

SERVER_PROCESS_RESTART_FLAG = False
HEARTBEAT_THREAD = None
BACKGROUND_THREADS_ENABLED = True
HEARTBEAT_DATA_RATE_FACTOR = 5

# cached copy of GENERAL/ADMIN_SOCKET_AUTH; kept in sync by 'on_set_config'
AdminAuth.set_admin_socket_auth_enabled(RaceContext.serverconfig.get_item('GENERAL', 'ADMIN_SOCKET_AUTH'))

ERROR_REPORT_INTERVAL_SECS = 600  # delay between comm-error reports to log

IMDTABLER_JAR_NAME =  PROGRAM_DIR + '/static/IMDTabler.jar'
NODE_FW_PATHNAME = "firmware/RH_S32_BPill_node.bin"

# check if 'log' directory owned by 'root' and change owner to 'pi' user if so
if RHUtils.checkSetFileOwnerPi(log.LOG_DIR_NAME):
    logger.info("Changed '{0}' dir owner from 'root' to 'pi'".format(log.LOG_DIR_NAME))

if __name__ == '__main__' and len(sys.argv) > 1:
    if CMDARG_VERSION_LONG_STR in sys.argv or CMDARG_VERSION_SHORT_STR in sys.argv:
        sys.exit(0)
    if CMDARG_ZIP_LOGS_STR in sys.argv:
        log.create_log_files_zip(logger, RaceContext.serverconfig.config_file_name, DB_FILE_NAME, PROGRAM_DIR)
        sys.exit(0)
    if CMDARG_MIN_MOCKS in sys.argv:
        minMocksArgIdx = sys.argv.index(CMDARG_MIN_MOCKS) + 1
        if minMocksArgIdx < len(sys.argv):
            try:
                minMocks = int(sys.argv[minMocksArgIdx])
            except ValueError:
                print("Invalid value for {} argument: {}".format(CMDARG_MIN_MOCKS, sys.argv[minMocksArgIdx]))
                sys.exit(1)
        else:
            print("Usage: python server.py {} N".format(CMDARG_MIN_MOCKS))
            sys.exit(1) 
    if CMDARG_VIEW_DB_STR in sys.argv:
        viewdbArgIdx = sys.argv.index(CMDARG_VIEW_DB_STR) + 1
        if viewdbArgIdx < len(sys.argv):
            if not os.path.exists(sys.argv[viewdbArgIdx]):
                print("Unable to find given DB file: {0}".format(sys.argv[viewdbArgIdx]))
                sys.exit(1)
        else:
            print("Usage: python server.py {0} dbFileName.db [pagename] [browsercmd]".format(CMDARG_VIEW_DB_STR))
            sys.exit(1)
    elif CMDARG_JUMP_TO_BL_STR not in sys.argv:  # handle jump-to-bootloader argument later
        if CMDARG_FLASH_BPILL_STR in sys.argv:
            flashPillArgIdx = sys.argv.index(CMDARG_FLASH_BPILL_STR) + 1
            ports = RaceContext.serverconfig.get_item('GENERAL', 'SERIAL_PORTS')
            flashPillPortStr = ports[0] if ports and len(ports) > 0 else None
            flashPillSrcStr = sys.argv[flashPillArgIdx] if flashPillArgIdx < len(sys.argv) else None
            if flashPillSrcStr and flashPillSrcStr.startswith("--"):  # use next arg as src file (optional)
                flashPillSrcStr = None                       #  unless arg is switch param
            flashPillSuccessFlag = stm32loader.flash_file_to_stm32(flashPillPortStr, flashPillSrcStr)
            sys.exit(0 if flashPillSuccessFlag else 1)
        elif CMDARG_LAUNCH_B_STR not in sys.argv and CMDARG_DATA_DIR not in sys.argv and CMDARG_MIN_MOCKS not in sys.argv:
            print("Unrecognized command-line argument(s): {0}".format(sys.argv[1:]))
            sys.exit(1)

# start SocketIO service
SOCKET_IO = SocketIO(APP, async_mode='gevent', cors_allowed_origins=RaceContext.serverconfig.get_item('GENERAL', 'CORS_ALLOWED_HOSTS'), max_http_buffer_size=5e7)

# this is the moment where we can forward log-messages to the frontend, and
# thus set up logging for good.
Current_log_path_name = log.later_stage_setup(RaceContext.serverconfig.get_section('LOGGING'), SOCKET_IO)

# Callback function invoked when an error-level message is logged
def log_error_callback_fn(*args):
    if not RaceContext.rhui.is_ui_message_set("errors-logged"):
        RaceContext.rhui.set_ui_message("errors-logged",\
                   f'{__("Error messages have been logged.")} (<a href=\"/hardwarelog?log_level=ERROR\">{__("View error log")}</a>)',\
                   header="Notice", subclass="errors-logged")
        if AdminAuth.Auth_succeeded_flag:
            SOCKET_IO.emit('update_server_messages', RaceContext.rhui.get_ui_server_messages_str())
    if check_log_error_alert():  # show alert popup if not previously shown
        log.set_log_level_callback(logging.NOTSET)  # if popup shown then clear callback function

log.set_log_level_callback(logging.ERROR, log_error_callback_fn)

RaceContext.sensors = Sensors()
RaceContext.cluster = None
RaceContext.rhdata = RHData.RHData(Events, RaceContext, SERVER_API, DB_FILE_NAME, DB_BKP_DIR_NAME) # Primary race data storage
RaceContext.pagecache = PageCache.PageCache(RaceContext, Events) # For storing page cache
RaceContext.language = Language.Language(RaceContext) # initialize language
__ = RaceContext.language.__ # Shortcut to translation function
Database.__ = __ # Pass language to Database module
Database.racecontext = RaceContext # Pass racecontext to Database module

RaceContext.race = RHRace.RHRace(RaceContext) # Current race variables
RaceContext.rhui = RHUI.RHUI(APP, SOCKET_IO, RaceContext, Events) # User Interface Manager
RaceContext.rhui.__ = RaceContext.language.__ # Pass translation shortcut
RaceContext.calibration = calibration.Calibration(RaceContext)
RaceContext.heatautomator = heat_automation.HeatAutomator(RaceContext)

# Wrapper to be used as a decorator on callback functions that do database calls,
#  so their exception details are sent to the log file (instead of 'stderr')
#  and the database session is cleaned up on exit (prevents DB-file handles left open).
def catchLogExcWithDBWrapper(func):
    @functools.wraps(func)
    def wrapper(*args, **kwargs):
        try:
            with RaceContext.rhdata.get_db_session_handle():  # make sure DB session/connection is cleaned up
                return func(*args, **kwargs)
        except:
            logger.exception("Exception via catchLogExcWithDBWrapper")
    return wrapper

# Return 'DEF_NODE_FWUPDATE_URL' config value; if not set in 'config.json'
#  then return default value based on BASEDIR and server RELEASE_VERSION
def getDefNodeFwUpdateUrl():
    try:
        if RaceContext.serverconfig.get_item('GENERAL', 'DEF_NODE_FWUPDATE_URL'):
            return RaceContext.serverconfig.get_item('GENERAL', 'DEF_NODE_FWUPDATE_URL')
        if RELEASE_VERSION.lower().find("dev") > 0:  # if "dev" server version then
            retStr = stm32loader.DEF_BINSRC_STR      # use current "dev" firmware at URL
        else:
            # return path that is up two levels from BASEDIR, and then NODE_FW_PATHNAME
            retStr = os.path.abspath(os.path.join(os.path.join(os.path.join(PROGRAM_DIR, os.pardir), \
                                                               os.pardir), NODE_FW_PATHNAME))
        # check if file with better-matching processor type (i.e., STM32F4) is available
        try:
            curTypStr = RaceContext.interface.nodes[0].firmware_proctype_str if len(RaceContext.interface.nodes) else None
            if curTypStr:
                fwTypStr = getFwfileProctypeStr(retStr)
                if fwTypStr and curTypStr != fwTypStr:
                    altFwFNameStr = RHUtils.appendToBaseFilename(retStr, ('_'+curTypStr))
                    altFwTypeStr = getFwfileProctypeStr(altFwFNameStr)
                    if curTypStr == altFwTypeStr:
                        logger.debug("Using better-matching node-firmware file: " + altFwFNameStr)
                        return altFwFNameStr
        except Exception as ex:
            logger.debug("Error checking fw type vs current type: " + str(ex))
        return retStr
    except:
        logger.exception("Error determining value for 'DEF_NODE_FWUPDATE_URL'")
    return "/home/pi/RotorHazard/" + NODE_FW_PATHNAME

# Returns the processor-type string from the given firmware file, or None if not found
def getFwfileProctypeStr(fileStr):
    rhIntfAccessObj = RaceContext.interface.get_rh_interface()
    if not rhIntfAccessObj:
        import MockInterface  #pylint: disable=import-error
        rhIntfAccessObj = MockInterface  # fall back to MockInterface so firmware-file parse will still work
    try:
        dataStr = stm32loader.load_source_file(fileStr, False)
        if dataStr:
            return RHUtils.findPrefixedSubstring(dataStr, rhIntfAccessObj.FW_PROCTYPE_PREFIXSTR, \
                                                 rhIntfAccessObj.FW_TEXT_BLOCK_SIZE)
    except Exception as ex:
        logger.debug("Error processing file '{}' in 'getFwfileProctypeStr()': {}".format(fileStr, ex))
    return None

# Shows an alert popup if error messages have been logged and popup was not previously shown
def check_log_error_alert():
    if AdminAuth.Auth_succeeded_flag and log.get_log_error_alert_flag():
        gevent.spawn_later(1.0, RaceContext.rhui.emit_priority_message,\
                f'{__("An error has occurred.")}<br /><a href="/hardwarelog?log_level=ERROR">{__("View error log")}</a>',\
                True, False, True)  # admin_only=True
        return True
    return False

#
# Authentication
#
# check_auth() and the SocketIO auth guard live in AdminAuth.py so RHUI.py
# can reuse them for plugin-registered handlers (RHAPI.socket_listen)
# without a circular import back to this module.

def check_default_admin_creds_warning():
    '''Sets/clears the admin-page warning for unchanged default admin credentials.'''
    username = RaceContext.serverconfig.get_item('SECRETS', 'ADMIN_USERNAME')
    password = RaceContext.serverconfig.get_item('SECRETS', 'ADMIN_PASSWORD')
    if username == 'admin' and password == 'rotorhazard':
        RaceContext.rhui.set_ui_message('default-admin-creds',
            __('Admin username/password are still set to their default values; change them below'),
            header='Warning', subclass='default-admin-creds')
    else:
        RaceContext.rhui.clear_ui_message('default-admin-creds')
    SOCKET_IO.emit('update_server_messages', RaceContext.rhui.get_ui_server_messages_str())

def apply_default_admin_creds_if_blank():
    '''If admin credentials are blank, set them to the default values.
    Called when Server Debug Mode is being turned off, since blank
    credentials are only a valid "no auth" setting while debug mode is
    on. Without this, disabling debug mode with blank credentials would
    lock out all admin access with no way back in through the web UI.
    '''
    if not RaceContext.serverconfig.get_item('SECRETS', 'ADMIN_USERNAME') and \
            not RaceContext.serverconfig.get_item('SECRETS', 'ADMIN_PASSWORD'):
        RaceContext.serverconfig.set_item('SECRETS', 'ADMIN_USERNAME', 'admin')
        RaceContext.serverconfig.set_item('SECRETS', 'ADMIN_PASSWORD', 'rotorhazard')
        RaceContext.rhui.emit_priority_message(
            __('Blank admin credentials are only allowed in Server Debug Mode; '
               'username/password have been set to their default values'),
            False, nobroadcast=True)
        # replies to the admin that triggered this, not a broadcast; do not change
        #  to 'SOCKET_IO.emit()', which would send the credentials to every client
        emit('admin_creds_defaulted', {
            'username': 'admin',
            'password': 'rotorhazard',
            })

def authenticate():
    '''Sends a 401 response that enables basic auth.'''
    return Response(
        'Could not verify your access level for that URL.\n'
        'You have to login with proper credentials', 401,
        {'WWW-Authenticate': 'Basic realm="Login Required"'})

def requires_auth(f):
    @functools.wraps(f)
    def decorated_auth(*args, **kwargs):
        if not AdminAuth.check_auth(RaceContext, request.authorization):
            return authenticate()
        return f(*args, **kwargs)
    return decorated_auth

requires_socketio_auth = AdminAuth.make_socketio_auth_guard(RaceContext)
# stricter guard for handlers that disclose a stored credential; not bypassable
#  via the 'Admin Socket Auth' setting
requires_socketio_credential_auth = AdminAuth.make_socketio_credential_guard(RaceContext)

# Flask template render with exception catch, so exception
# details are sent to the log file (instead of 'stderr').
def render_template(template_name_or_list, **context):
    try:
        check_log_error_alert()
        context.update({
            'serverInfo': RaceContext.serverstate.template_info_dict,
            'getOption': RaceContext.rhdata.get_option,
            'get_optionInt': RaceContext.rhdata.get_optionInt,
            'get_optionNumeric': RaceContext.rhdata.get_optionNumeric,
            'getConfig': RaceContext.serverconfig.get_item,
            '__': __,
            'Debug': RaceContext.serverconfig.get_item('GENERAL', 'DEBUG'),
            'restart_flag': RaceContext.serverstate.restart_required
        })
        response = make_response(templating.render_template(template_name_or_list, **context))
        response.cache_control.no_store = True
        return response
    except Exception:
        logger.exception("Exception in render_template")
    return "Error rendering template"

# Handler for closing and deallocating database resources
@APP.teardown_appcontext
def shutdown_session(exception=None):
    if Database.DB_session:
        Database.DB_session.remove()

#
# Routes
#
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

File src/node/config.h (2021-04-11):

#ifndef config_h
#define config_h

#include <Arduino.h>
#include "util/rhtypes.h"

#ifdef STM32_CORE_VERSION
#define STM32_MODE_FLAG 1  // 1 for STM 32-bit processor running multiple nodes
#else
#define STM32_MODE_FLAG 0  // 0 for Arduino processor running single node
#endif

#if !STM32_MODE_FLAG

// Set to 1-8 for manual selection of Arduino node ID/address
// Set to 0 for automatic selection via hardware pin
// See https://github.com/RotorHazard/RotorHazard/wiki/Specification:-Node-hardware-addressing
#define NODE_NUMBER 0

#endif

// ******************************************************************** //

// features flags for value returned by READ_RHFEAT_FLAGS command
#define RHFEAT_STM32_MODE ((uint16_t)0x0004)      // STM 32-bit processor running multiple nodes
#define RHFEAT_JUMPTO_BOOTLDR ((uint16_t)0x0008)  // JUMP_TO_BOOTLOADER command supported
#define RHFEAT_IAP_FIRMWARE ((uint16_t)0x0010)    // in-application programming of firmware supported
#define RHFEAT_NONE ((uint16_t)0)

#if STM32_MODE_FLAG
// value returned by READ_RHFEAT_FLAGS command
#define RHFEAT_FLAGS_VALUE (RHFEAT_STM32_MODE | RHFEAT_JUMPTO_BOOTLDR | RHFEAT_IAP_FIRMWARE)

#define SERIAL_BAUD_RATE 921600
#define MULTI_RHNODE_MAX 8
#define STM32_SERIALUSB_FLAG 0  // 1 to use BPill USB port for serial link

#else
// value returned by READ_RHFEAT_FLAGS command
#define RHFEAT_FLAGS_VALUE RHFEAT_NONE

#define SERIAL_BAUD_RATE 115200
#define MULTI_RHNODE_MAX 1
#endif  // STM32_MODE_FLAG


#if STM32_MODE_FLAG || defined(__TEST__)
#define ATOMIC_BLOCK(x)
#define ATOMIC_RESTORESTATE
#else
#include <util/atomic.h>
#endif

#if !STM32_MODE_FLAG

// Set to 0 for standard RotorHazard node wiring; set to 1 for ArduVidRx USB node wiring
//   See here for an ArduVidRx example: http://www.etheli.com/ArduVidRx/hw/index.html#promini
#define ARDUVIDRX_WIRING_FLAG 0

#define CHORUS_WIRING_FLAG 0

#if ARDUVIDRX_WIRING_FLAG
#define RX5808_DATA_PIN 10             //DATA output line to RX5808 module
#define RX5808_SEL_PIN 11              //SEL output line to RX5808 module
#define RX5808_CLK_PIN 12              //CLK output line to RX5808 module
#define RSSI_INPUT_PIN A7              //RSSI input from RX5808
#define NODE_RESET_PIN A1              //Pin to reset paired Arduino via command for ISP
#elif CHORUS_WIRING_FLAG
#define RX5808_DATA_PIN 10             //DATA output line to RX5808 module
#define RX5808_SEL_PIN 11              //SEL output line to RX5808 module
#define RX5808_CLK_PIN 12              //CLK output line to RX5808 module
#define RSSI_INPUT_PIN A3              //RSSI input from RX5808
#define NODE_RESET_PIN A1              //Pin to reset paired Arduino via command for ISP
#else
#define RX5808_DATA_PIN 11             //DATA output line to RX5808 module
#define RX5808_SEL_PIN 10              //SEL output line to RX5808 module
#define RX5808_CLK_PIN 13              //CLK output line to RX5808 module
#define RSSI_INPUT_PIN A0              //RSSI input from RX5808
#define NODE_RESET_PIN 12              //Pin to reset paired Arduino via command for ISP
#endif

#define DISABLE_SERIAL_PIN 9  //pull pin low (to GND) to disable serial port
#define HARDWARE_SELECT_PIN_1 2
#define HARDWARE_SELECT_PIN_2 3
#define HARDWARE_SELECT_PIN_3 4
#define LEGACY_HARDWARE_SELECT_PIN_1 4
#define LEGACY_HARDWARE_SELECT_PIN_2 5
#define LEGACY_HARDWARE_SELECT_PIN_3 6
#define LEGACY_HARDWARE_SELECT_PIN_4 7
#define LEGACY_HARDWARE_SELECT_PIN_5 8

#define MODULE_LED_ONSTATE HIGH
#define MODULE_LED_OFFSTATE LOW

#else  // STM32_MODE_FLAG

#define RX5808_DATA_PIN PB3            //DATA output line to RX5808 modules
#define RX5808_CLK_PIN PB4             //CLK output line to RX5808 modules

#define RX5808_SEL0_PIN PB6            //SEL output lines to RX5808 modules
#define RX5808_SEL1_PIN PB7
#define RX5808_SEL2_PIN PB8
#define RX5808_SEL3_PIN PB9
#define RX5808_SEL4_PIN PB12
#define RX5808_SEL5_PIN PB13
#define RX5808_SEL6_PIN PB14
#define RX5808_SEL7_PIN PB15

#define BUZZER_OUTPUT_PIN PA8
#define BUZZER_OUT_ONSTATE LOW
#define BUZZER_OUT_OFFSTATE HIGH

#define AUXLED_OUTPUT_PIN PA15

#ifndef STM32_F4_PROCTYPE  // pinouts for STM32F103C8T6 "Blue Pill" module

#define RSSI_INPUT0_PIN A0             //RSSI inputs from RX5808 modules
#define RSSI_INPUT1_PIN A1
#define RSSI_INPUT2_PIN A2
#define RSSI_INPUT3_PIN A3
#define RSSI_INPUT4_PIN A4
#define RSSI_INPUT5_PIN A5
#define RSSI_INPUT6_PIN A6
#define RSSI_INPUT7_PIN A7

#define VOLTAGE_MONITOR_PIN PB1

// on the S32_BPill PCB this pin is connected to RPi GPIO24, which should be
//  configured for "heartbeat" on the RPi in "/boot/config.txt" like this:
//    dtoverlay=act-led,gpio=24
//    dtparam=act_led_trigger=heartbeat
#define RPI_SIGNAL_PIN PB0
#define RPI_SIGNAL_ONSTATE HIGH

#else                   // pinouts for STM32F411CEU6 "Black Pill" module
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

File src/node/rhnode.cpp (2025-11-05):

#ifndef __TEST__
// RotorHazard FPV Race Timing
// Based on Delta 5 Race Timer by Scott Chin
// SPI driver based on fs_skyrf_58g-main.c Written by Simon Chambers
// I2C functions by Mike Ochtman
//
// MIT License
//
// Copyright (c) 2019 Michael Niggel and other contributors
//
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
#include "config.h"
#include "RssiNode.h"
#include "commands.h"
#if !STM32_MODE_FLAG
#include <Wire.h>
#endif

// Note: Configure Arduino NODE_NUMBER value in 'config.h'

// firmware version string (prefix allows text to be located in '.bin' file)
const char *firmwareVersionString = "FIRMWARE_VERSION: 1.2.0";

// build date/time strings
const char *firmwareBuildDateString = "FIRMWARE_BUILDDATE: " __DATE__;
const char *firmwareBuildTimeString = "FIRMWARE_BUILDTIME: " __TIME__;

// node processor type
#if !STM32_MODE_FLAG
const char *firmwareProcTypeString = "FIRMWARE_PROCTYPE: Arduino";
#else
#if !STM32_F4_PROCTYPE
const char *firmwareProcTypeString = "FIRMWARE_PROCTYPE: STM32F1";
#else
const char *firmwareProcTypeString = "FIRMWARE_PROCTYPE: STM32F4";
#endif
#endif

#if !STM32_MODE_FLAG
// i2c address for node
// Node 1 = 8, Node 2 = 10, Node 3 = 12, Node 4 = 14
// Node 5 = 16, Node 6 = 18, Node 7 = 20, Node 8 = 22
uint8_t i2cAddress = 6 + (NODE_NUMBER * 2);
#define SERIALCOM Serial
#define COMMS_MONITOR_TIME_MS 5000 //I2C communications monitor grace/trigger time

#else
#define MIN_RSSI_DETECT 5          //value for detecting node as installed
#if STM32_SERIALUSB_FLAG
#define SERIALCOM SerialUSB
#else
#define SERIALCOM Serial
#endif
#endif

// dummy macro
#define LOG_ERROR(...)

Message serialMessage;

#if !STM32_MODE_FLAG
Message i2cMessage;

// Defines for fast ADC reads
#define cbi(sfr, bit) (_SFR_BYTE(sfr) &= ~_BV(bit))
#define sbi(sfr, bit) (_SFR_BYTE(sfr) |= _BV(bit))

void i2cInitialize(bool delayFlag);
void i2cReceive(int byteCount);
bool i2cReadAndValidateIoBuffer(byte expectedSize);
void i2cTransmit();

#elif STM32_SERIALUSB_FLAG
void serialEvent();
#endif

void setModuleLed(bool onFlag);

#if defined(RPI_SIGNAL_PIN) || defined(AUXLED_OUTPUT_PIN) || defined(BUZZER_OUTPUT_PIN)
void handleRpiSignalAndShutdownActions(mtime_t curTimeMs);
#endif

#ifdef RPI_SIGNAL_PIN
static volatile bool rpiActiveSignalFlag = false;
static volatile mtime_t rpiLastActiveTimeMs = 0;
#define RPI_INACTIVE_DELAYMS 9000  // if no RPi signal for this long then "inactive"
#define RPI_MISSING_DELAYMS 2000
#define GET_RPI_ACTIVESIG_FLAG() (rpiActiveSignalFlag)
#define GET_RPI_LASTACTIVE_TIMEMS() (rpiLastActiveTimeMs)
// have AUX LED mostly on if RPi status is "active"
#define AUXLED_OUT_ONSTATE (rpiActiveSignalFlag ? LOW : HIGH)
#define AUXLED_OUT_OFFSTATE (rpiActiveSignalFlag ? HIGH : LOW)
#else
#define GET_RPI_ACTIVESIG_FLAG() (false)
#define GET_RPI_LASTACTIVE_TIMEMS() (0)
#define AUXLED_OUT_ONSTATE HIGH
#define AUXLED_OUT_OFFSTATE LOW
#endif

#ifdef AUXLED_OUTPUT_PIN
static volatile bool auxLedOutEnabledFlag = false;
#endif

#ifdef BUZZER_OUTPUT_PIN
void setBuzzerState(bool onFlag);
static volatile int buzzerBeepDurationCounter = 0;
static volatile int lastCommActivityTimeMs = 0;
#endif

#if defined(AUXLED_OUTPUT_PIN) || defined(BUZZER_OUTPUT_PIN)
static volatile bool shutdownButtonPressedFlag = false;
static volatile bool shutdownHasBeenStartedFlag = false;
static volatile bool rpiSignalMissingFlag = false;
#endif

#if (!STM32_MODE_FLAG) && ((!defined(NODE_NUMBER)) || (!NODE_NUMBER))
// Configure the I2C address based on input-pin level.
void configI2cAddress()
{
    // current hardware selection
    pinMode(HARDWARE_SELECT_PIN_1, INPUT_PULLUP);
    pinMode(HARDWARE_SELECT_PIN_2, INPUT_PULLUP);
    pinMode(HARDWARE_SELECT_PIN_3, INPUT_PULLUP);
    // legacy selection - DEPRECATED
    pinMode(LEGACY_HARDWARE_SELECT_PIN_1, INPUT_PULLUP);
    pinMode(LEGACY_HARDWARE_SELECT_PIN_2, INPUT_PULLUP);
    pinMode(LEGACY_HARDWARE_SELECT_PIN_3, INPUT_PULLUP);
    pinMode(LEGACY_HARDWARE_SELECT_PIN_4, INPUT_PULLUP);
    pinMode(LEGACY_HARDWARE_SELECT_PIN_5, INPUT_PULLUP);

    delay(100);  // delay a bit a let pin levels settle before reading inputs
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

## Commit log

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2023-05-24 Fix adaptive calibration issue
    fix profile reference not updated
    [server.py]
2023-05-26 Move builtin actions to bundled plugin
    Also catch/log issues for all called effects
    [EventActions.py, server.py]
2023-05-30 Added check for 'heatNode_data' size in RHUI
2023-05-30 Fix /api/race/current return json
    The /api/race/current endpoint was returning KeyError.
2023-06-04 Update jquery and socket-io versions
2023-06-04 Add rank by last heat position
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2023-06-06 Coverage for existing Heat Generator methods
2023-06-13 Add heatgen and LED access
2023-06-13 Add hardware interface and migrate LED
2023-06-19 Set default names Climate and Battery on sensors
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2023-06-24 add NuelcarHazard files
    [NuclearHazard_BOM.csv, NuclearHazard_PickAndPlace.csv]
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2023-06-29 Fix RHAPI slots_alter_fast
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2023-06-30 Fix heat advance UI
2023-06-30 Class ranking stability
    Match expected return values
    Handle failure case
2023-07-01 Fix UI issue
    changing pilots on currently selected race when method = None
2023-07-03 Fixed persisting of current race format
    [server.py]
2023-07-03 Mods to 'restore_database_file()' to address DB-session issues
    [server.py]
2023-07-04 Fixed not connecting to sec timer at startup
    [ClusterNodeSet.py]
2023-07-04 Added optional param to VRxControl 'kill'
    to address errors on split timer connect
    [VRxControl.py]
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2023-07-21 Update unit tests, fix profile resolver
    [server.py]
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2023-08-07 Fix errant frequency change indicator
    [server.py]
2023-08-07 Fixed 'with no ClusterSendAckQueueObj' issue
    [ClusterNodeSet.py, server.py]
2023-08-07 Make sure nodes on Current page (1st race) updated on heat change
2023-08-18 Update onsphape link to new version of case
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2023-08-21 Fix RHAPI heat add/alter
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2023-09-07 Fix overwriting current heat designation during race
    [server.py]
2023-09-07 Also clear current race on full reset
    [server.py]
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2023-11-04 add v5 nuclearhazard files
    [NuclearHazard_BOM.csv, NuclearHazard_PickAndPlace.csv]
2023-11-13 Prevent potential stall of speak queue processing
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2023-12-08 Bug fixes and cleanup
    [calibration.py, server.py]
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2024-01-02 Data attributes for heats, classes, and races (meta)
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2024-01-12 Fix sequential assumption for dataloggers
    [RHInterface.py]
2024-01-14 Fix 'clock_check_thread_function()' time correction
    [server.py]
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2024-01-21 Fix bug in server 'on_join_cluster_ex()' fn
    [server.py]
2024-01-23 Periodic sensor logging (#844)
    * Periodic sensor logging
    Resolves #353
    [Config.py, server.py]
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2024-01-26 Remove load/save buttons from Marshal UI if calibration is adaptive
2024-01-30 Improved import error handling in RH_GPIO
    [RH_GPIO.py]
2024-02-01 Remove event handler kill and prevent LED shutdown (#853)
    * Always clear at shutdown
    * Remove SHUTDOWN from configurable list
    * Provide a proper method for LED effects to terminate
    * Improvements to led_effects_manager and strip handler
    * New method for effect trigger/exit
    * simplify effect termination
    * Prevent same object re-use
    * shutdown handling cleanup
    * stability and code style adjustments
    * apply effect delay and bump plugin versions
    * Document API changes
    * Redo argument simplifiaction
    * Restore preventIdle
    ---------
    [eventmanager.py, server.py]
2024-02-05 Prevent UnboundLocalError in led_event_manager get_idle_fn()
2024-02-19 Removed reference to Eclipse in Arduino Nodes doc
2024-02-20 Addressed issues with database restore/close
    [server.py]
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2024-02-29 Squlech 'switching to practice mode' log msgs at startup
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2024-03-14 Fixes for database connections building up
    [ClusterNodeSet.py, Database.py, server.py]
2024-03-25 Fixed bug in LEDCtrlr interface code
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2024-03-30 When archiving database also do it on split timers
2024-04-05 Force immediate save and prevent secondary heat use
2024-04-08 Fixed issue starting up with no database file
    [Database.py, server.py]
2024-04-11 Pre-fixing merge conflicts for PR #869
    [server.py]
2024-04-11 Migrate config to class and provide API endpoints (#869)
    * Migrate Config into class and provide RHAPI
    * move secrets to unique section, remove config-dist
    * sharable config
    * Minor cleanup
    * Migrate server items from db to config
    * Migrate items to config
    * Post-merge fixes
    * Config migrations and cleanup
    * RHAPI backward compatibility, warn for deprecated usage
    * Bug fixes and cleanup
    * Cleanup
    * Cleanup and bug fix
    * Correction for Marshaling
    * Differentiate config sections
    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
    [ClusterNodeSet.py, Config.py, EventActions.py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]
2024-04-11 Process race save results incrementally (PR #888)
    https://github.com/RotorHazard/RotorHazard/pull/888
2024-04-13 Fix heat and class assignment swap
2024-04-15 Fixed usage of 'config' by 'hardwareHelpers'
    [server.py]
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2024-04-22 Fixed issues with 'ledBrightness' value type
    [Config.py, server.py]
2024-04-22 Prevent 'linux_sensor' from throwing ValueError exceptions
    [linux_sensor.py]
2024-04-23 Handle errors and idler=None in LED 'effect_runner()'
2024-04-23 Updated text for split timer audio settings on Run page
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2024-04-23 Handle combining hole shot and staggered results
    Move staggered results to total_laps
    Remove format processing in sort_and_rank
    Populate most meta before sorting
    Warn about unformatted calc data
2024-04-25 Fix to allow empty username/password values
    [Config.py]
2024-04-26 Fix heat automation not assigning from class
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2024-04-28 Fixed references to 'calibrationMode' setting on html pages
2024-04-30 NuclearHazard: refactor some Core stuff, add Atom
    [Atom BOM.csv, Atom Case.stl, Atom Lid.stl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]
2024-05-08 Fixed issue where changes to Event Actions were not propagating
    [EventActions.py]
2024-05-28 Fix issue with switching from 'None' to pilot in heat (#908)
    * Fixed issue with switching from 'None' to pilot in heat
    * Remove redundancy
    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
2024-06-02 Fixed bug ('AttributeError') with secondary timer
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2024-06-05 added plugin support for generating heat slots which are seeded by class rank
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2024-07-17 Handle switching and selection
    Auto-switch on deactivate
    Check active on heat set
    Prevent startup selection
    [server.py]
2024-07-20 Added some pylint directives for 'import-error'
    [RH_GPIO.py]
2024-07-21 Added note for NuclearHazard shutdown button on GPIO19
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2024-07-22 Added support for Event Actions on split timers
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2024-08-17 Fixed setting of EventActionsObj global
    [server.py]
2024-08-17 Fixed setting of ShutdownButtonInputHandler global
    [server.py]
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2024-08-28 Bug fixes and cleanup
    - Adjust round display
    - Fix UI updating on round change
    - Remove 'never' option for advance when grouped
    - Fix missing heat add button
    - Fix heat selector on Run
    - Improve next heat/next class selection
    - Reset active status on clear
    [Database.py, server.py]
2024-08-28 More results optimization
    - Reduce calc_leaderboard to single-race processing
    - Convert current laps to object/dataclass
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2024-09-05 Heat generation fixes
2024-09-15 Fixed 'lap_time_stamp' usage in ClusterNodeSet
    [ClusterNodeSet.py]
2024-09-16 Fixed setting of Use_imdtabler_jar_flag global
    [server.py]
2024-09-27 Handle serialized and unserialized crossings in LED handlers
2024-09-29 update nuclearhazard core to v8
    [NuclearHazard_BOM.csv, NuclearHazard_PickAndPlace.csv]
2024-10-01 Fix LED RSSI graphing
    Closes #959
2024-10-01 Fix reassignment of unclassified heat
    Fixes #955
2024-10-08 Modified time-correction params on emitToSplits
    [ClusterNodeSet.py]
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2024-10-09 Functional publish and receive for heat and class attributes
2024-10-12 add missing localizations (#957)
    * add missing localizations
    * add missing localizations for node update page
    * add missing localizations for node update page
    * Improve Simplified Chinese Localization
    * Improve Simplified Chinese Localization
    * The non-text parts need to be separated
    * The non-text parts need to be separated
    [ClusterNodeSet.py, server.py]
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2024-11-11 Round-less name (if group) and modify text replacer
    [Database.py]
2024-11-22 Fixed missing-lines issue on Server Log filtered view
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2024-12-03 Fix PANEL_ROTATE on 4-node count LED effect
2024-12-09 Fixed bug with team race winner event action
    [EventActions.py]
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2024-12-12 Prevent exception on improper data access
    [server.py]
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2025-01-03 Prevent cluster emitter from modifying source
    [ClusterNodeSet.py]
2025-01-14 Fix --data and log data path
    [server.py]
2025-01-15 Bug fixes and stability
    [Config.py]
2025-01-16 Add restart server function
    Doesn't release the network entirely, so reloading from the same browser requires waiting for a lengthy timeout. Using a different browser works immediately.
    [server.py]
2025-01-17 Replaced 'is not' with '!=' to fix warning message
    [ClusterNodeSet.py]
2025-01-19 Show race duration on initial Run/Current timer in Co-op mode
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2025-02-12 Fix plugin path with variable data dir
    [server.py]
2025-02-15 Bug fixes and unclassified heat support
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2025-03-01 Fixed usages of method.name
    [data_export.py, data_import.py]
2025-03-03 Fix heat and class unlocking
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2025-03-07 update race name in rotorhazard to be consistent with fpvtrackside race name
2025-03-08 Send null if bracket is set to None
2025-03-08 Reverse logic for bracket
2025-03-08 fix heat id
2025-03-13 fix bracket
2025-03-25 Fixed 'Download Event Database' button when no DBs available
    [server.py]
2025-03-30 Address plugin loading issues - Fix offline startup issue - Fix loading of plugins from the data directory - Change some code formating in the plugin installation file
    [server.py]
2025-03-31 Fix LED_ROWS minimum
    - catch divide by zero if < 1
    - prevent setting < 1 in config editor
    [ANSI_leds.py, cv2_leds.py]
2025-03-31 Fix LED_ROWS minimum
2025-04-05 create a proper db_test.py benchmarking file, fix a bug in the config changes used to database.py
    [Database.py]
2025-04-06 Fix display routine for grouped-heat view
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2025-04-14 Fix parameter error in 'clean_config()'
    [Config.py]
2025-04-16 Fix registered config section overwriting
    [Config.py]
2025-04-17 Fix population of persistent UIFields
    [Config.py]
2025-04-19 Fixed 'Backup/Download Database' button fn
    [server.py]
2025-04-20 Revert reassignment of stdout if ANSI_leds in use
    [server.py]
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2025-04-23 Fix reassign to null class
    Also skip and alert user on self-reassignment
    [server.py]
2025-05-02 Fixed access to 'IMDTabler.jar' when dataDir != programDir
    [server.py]
2025-05-07 Fix passing of peak data
    [BaseHardwareInterface.py]
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2025-05-08 Only set heat after confirming if called from "run" page
2025-05-08 Set current heat to none after reverting seed
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2025-05-13 Heat and class atomic updating
    Re-uses existing elements in place instead of re-appending an updated version
2025-05-14 Fix default heat/class seed
2025-05-14 Fix seeded heat/class selectors
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2025-05-15 Fix heat unlocking
2025-05-20 Migrate attributes with heat ID reassignment
    Fixes #1046
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2025-05-23 Manage grouped heats during reassignment
    fixes #1016
    [server.py]
2025-05-23 Use descriptive text for error link
    Avoids "click here"
    [server.py]
2025-05-29 Invoke split timer events even if effect not configured
2025-06-03 Prevent template pages from caching
    [server.py]
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2025-06-13 Move SPI mod info out of Arduino setup
2025-06-20 Fix doc and image loaders
    [server.py]
2025-07-01 revert to JavaScript-based localization
    [server.py]
2025-07-10 Fix group selector for heat additions
    [server.py]
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2025-07-16 Force method to pilot only if heat is unconfirmed
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2025-08-01 bug fixes and dialog improvement
    [server.py]
2025-08-01 Code style and bug fixes
    [server.py]
2025-08-26 Fixes for standard marshaling
    [server.py]
2025-09-11 Rename UI Variable to UI Function Binding
    [server.py]
2025-09-30 Bug fixes and test updates
    [server.py]
2025-10-04 Add mock types
    * Adds default "none" type
    * Returns file load functionality
    Requires Python 3.10 support for match/case—this was going to be bumped up anyway since 3.9 is EOL Oct 30
2025-10-22 Prevent foreign key issues when clearing data
    [server.py]
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2025-10-30 Create server message for failed register test
    [RHInterface.py, server.py]
2025-10-30 Add retry when frequency doesn't validate
    [RHInterface.py]
2025-10-31 Fix heat deletion: clear foreign key relationships
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2025-11-04 Prevent enter/exit input error
    [calibration.py, server.py]
2025-11-06 Improve discovery of ESP32/Arduino serial nodes (#1089)
    * add a small buffer for esp32 based boards
    * move flush to discover, that way esp32 boards get a proper buffer flush before discovery, and once before first write
    * some kind of sleep/chill_time is required for esp32 boards on serial open
    * Improve discovery of ESP32/Arduino serial nodes
    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
2025-11-08 Supply context to filters (#1097)
    * Add context args to filters
    * RHAPI access
    * Documentation
2025-11-10 Fix exporting for unclassified
    [server.py]
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2025-11-28 Updates for 'rh_led_handler_graph' plugin support for LED strips
2025-12-01 Updated Socket Headers for RotorHazard S32_BPill PCB doc
2025-12-06 add slot preassignment
    preassignment: {
    slot id : node index
    }
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2025-12-12 Move filter and prevent duplicate seat use
2025-12-14 Fix STM32 reported as missing when present but no nodes detected
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2025-12-14 Fix detection of USB nodes on S32_BPill
    [serial_node.py]
2025-12-14 Auto-frequency function filter
    Allows override of auto-freq function
    Ensure filtered output is callable
    Perfromance: store reused args in a var vs. repeated function calls
2025-12-19 Interface ready property and failure message
    [BaseHardwareInterface.py, server.py]
2025-12-27 Minimum first crossing (ignore before) (#1104)
    * Minimum first crossing (ignore before)
    * Fix indents
    * Apply min-first-crossing logic to peak tracking marshal
    * post-race peak marshal and corrections
    [MockInterface.py, eventmanager.py, server.py]
2025-12-27 Permissive scheduler (#1114)
    * Permissive scheduler
    Includes flag to allow scheduler to save stopped races
    * API access and prevent self-termination
    * Action access
    * UI timer corrections
    * Document RHAPI change
    * Revert unintended IDE change
    [server.py]
2025-12-29 Improve error handling when initializing serial nodes
    [serial_node.py, server.py]
2025-12-29 Improve documentation for shutdown button GPIO and config.json
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2026-05-27 Reorder DB wipe Clear heats before classes to avoid foreign key error
2026-07-03 Restore expire thread debug message on premature race exit
2026-09-15 Adjustments to RHAPI to allow for FPVTrackside connector to do marshalling.
2026-09-15 Address review feedback on pilotrun_alter/resave_pilotrun
    - Move the last_race in-memory sync (results, laps, leaderboard/laps emit)
    into resave_pilotrun() so both the web handler and RHAPI.db.pilotrun_alter
    keep it up to date, not just the web Marshal page.
    - Document lap_time_stamp/lap_time as required fields of the laps list in
    RHAPI.md, rather than optional.
    - Log a warning and return in on_resave_laps when resave_pilotrun fails to
    resolve pilotrace_id, instead of continuing as if it succeeded.
    - Drop the docstring from pilotrun_alter to match RHAPI.py convention.
    - Cover the last_race sync in test_pilotrun_alter.
    [server.py]
2026-09-16 Revert "Gracefully catch intentional update loop exits"
    Change did not have intended effect.
    [MockInterface.py, RHInterface.py, server.py]
2026-09-17 Fix infinite loop pruning node RSSI history
    The prune loop in process_history() recomputed `monotonic() - 60` in the
    while condition, so the cutoff advanced on every iteration. If the loop ran
    long enough to keep pace with the moving cutoff it never exited, pinning the
    update thread at 100% CPU. Because gevent is cooperatively scheduled and this
    loop has no yield point, the whole server stops responding: the web UI times
    out and no other greenlet runs again.
    Seen on a Pi 3B+ with the server wedged in this loop; py-spy showed the same
    invocation still running 10s apart (identical `readtime` local) and 30/30
    samples inside the loop body.
    Compute the cutoff once before the loop and bound the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
    [BaseHardwareInterface.py]
2026-09-17 Fetch current enter/exit levels from server on marshal Load from Node
2026-09-27 Fix reassigning a race to an unclassified heat that already has races
2026-09-27 Show round, heat and class from the parent race in the database page Saved Races table
2026-09-29 Add RHAPI race.laps_replace() to replace a seat's laps in the current race
2026-10-05 Authenticate the primary timer to secondary timers that require admin credentials
2026-10-08 Fix add_fastest_race_lap_meta() wiping a correct fastest-lap summary on rebuilt heat, class and event results
2026-10-10 Shorten plugin-interface comments, note initialize_rh_interface() expects cleared interfaces, and test the startup order
    [server.py]
2026-10-12 Add Delete This Round button to the Marshal page
2026-10-16 Add Deleted Races section with Restore buttons to the Database page
2026-10-16 Report changes to the heat's next round to clients and in Evt.RACE_DELETE and Evt.RACE_RESTORE data
2026-10-16 Refuse deleting or restoring a race while a race in its heat is in progress
2026-10-17 Add a View Deleted Rounds button to Data Management
2026-10-18 Add a Clear button to the errors-logged notice in server-debug mode
2026-10-24 Focus number inputs when their spin buttons are clicked
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2026-10-29 Move server-pushed speech handling into rotorhazard.js so all pages speak
2026-11-09 Add x-range zoom and navigation to the marshal graph
    The marshal graph always showed the whole race, so on long races the
    individual RSSI peaks were too narrow to inspect. The visible time range
    can now be limited (from/to in seconds, zoom in/out, full race,
    Ctrl+wheel zoom, Shift+wheel pan), and the zoomed view can be moved to
    the start/end or by 25% of its width.
    Smoothie drops data scrolled off the left edge while rendering, so
    maxDataSetLength is set to Infinity to keep it when zooming.
2026-11-09 Rework auto-calibration EnterAt/ExitAt suggestions (#1185)
    * Leave late laps out of the auto-calibration noise count and score
    * Stop weighting auto-calibration scores toward the currently recorded lap count
    * Score auto-calibration ExitAt on crossing time and place it near the top of the clean range
    * Keep a single noisy EnterAt from splitting a clean auto-calibration band
    * Step auto-calibration EnterAt down for a weak holeshot only when the later passes stay the same
    * Handle races stopped mid-crossing and the landing after unlimited races in auto-calibration
    * Count auto-calibration laps only up to the winning lap in first-to-laps races
    * Ignore noise crossings after the last pass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
2026-11-10 Zoom the marshal graph with the mouse wheel and scroll it by dragging
2026-11-12 Skip pilot races with no laps when finding adaptive calibration values
